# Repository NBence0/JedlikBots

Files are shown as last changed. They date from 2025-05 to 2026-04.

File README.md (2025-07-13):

# JedlikBots – Future Robotics Engineers from Győr, Hungary
<p align="center">
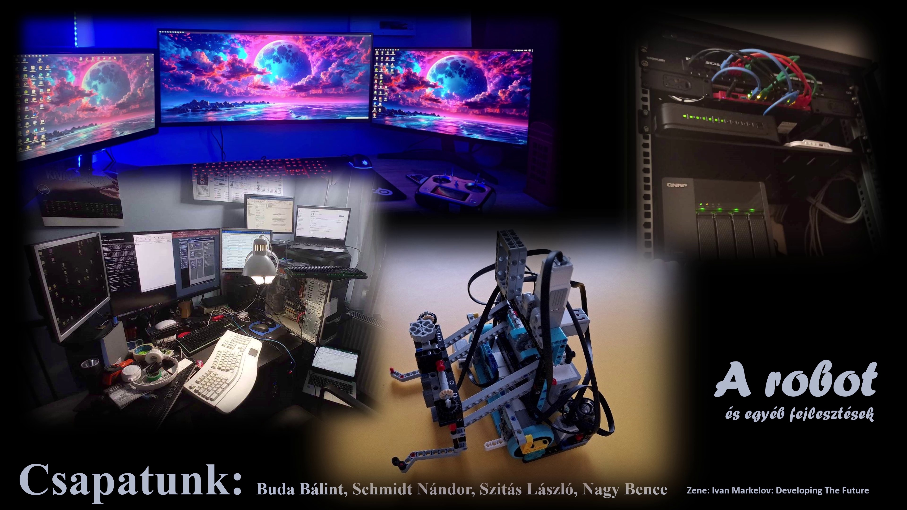
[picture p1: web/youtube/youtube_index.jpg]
JedlikBots Banner
  
</p>

Welcome to the official GitHub page of **JedlikBots**! 🎓🤖 We are the dedicated team of software development and robotics students from the Jedlik Ányos Technical School in Győr, Hungary. Our passion is to combine mechanical engineering, electronics, and software development to create innovative robotics solutions that address real-world problems. Our goal is to apply our acquired knowledge in national and international competitions and to inspire the next generation of engineers.

---

## 🚀 Our Main Project: ProBot X1 – The Next Generation of Competition Robots

The **ProBot X1** is our team's flagship project: a professional, modular robot platform specifically designed for the **WRO (World Robot Olympiad)** international competition series and other high-level technological challenges. During the robot's development, we use state-of-the-art technologies to create a truly competitive and versatile device.

<p align="center">
  ProBot X1 Prototype
  <br>
  <em>The early but functional prototype of the ProBot X1 in its development environment.</em>
</p>

---

## 🔧 Technical Deep Dive: The Anatomy of ProBot X1

The ProBot X1 is not just a robot—it's a complex system designed and built with precision engineering. Below, we provide a detailed overview of the project's technical background.

### 1. Mechanical Design and Manufacturing Philosophy

The robot's physical frame and all mechanical components are entirely custom-designed. Our design philosophy centers around **modularity**, **robustness**, and **rapid iteration**.

*   **Design Software:** We create our models in professional CAD software, where every component is designed down to the smallest detail.
*   **Manufacturing Technology:** The parts are produced using 3D printing. This allows us to test new prototypes within days and flexibly adapt the robot's structure to the specific requirements of a given competition task.
*   **Material Selection:** We use PLA for prototypes and PETG or ABS for the final, high-stress components to ensure adequate strength and durability.

| Design in CAD Software (Video) | The Finished, Printed Components |
| :---: | :---: |
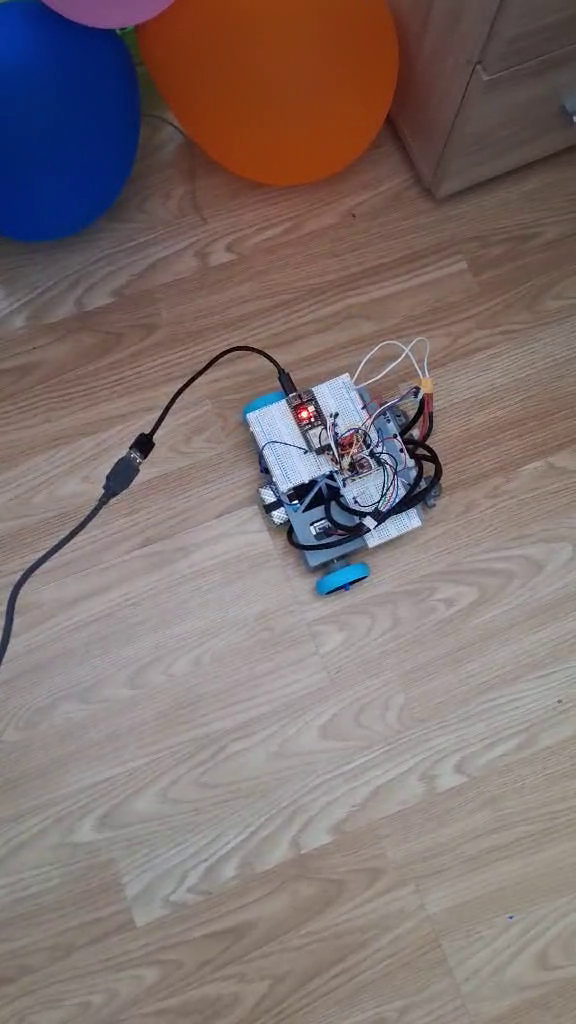
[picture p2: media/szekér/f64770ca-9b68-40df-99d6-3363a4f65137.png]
Robot Design Process Video
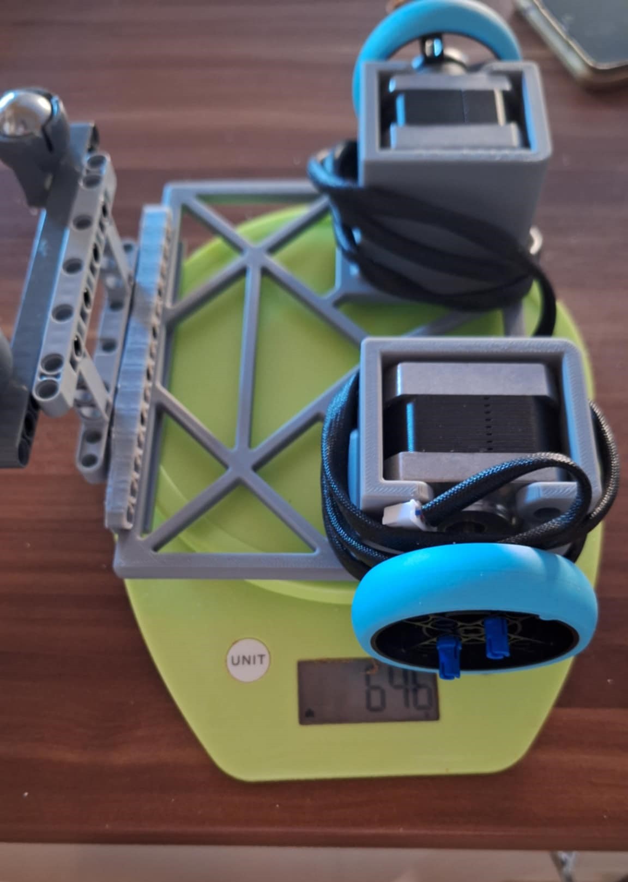
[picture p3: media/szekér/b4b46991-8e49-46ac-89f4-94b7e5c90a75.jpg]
Printed Robot Components
|  |  |
<p align="center"><em>On the left, the design process (click for video!), and on the right, the finished, printed components next to measurement instruments. The lattice structure provides optimal rigidity with minimal weight.</em></p>

### 2. Advanced Electronics and Custom-Designed PCB

The robot's brain and nervous system are comprised of a custom Printed Circuit Board (PCB) designed by us, located in the `Circuit/kicad/Robot fő nyák_v3/` folder. Our goal was to create a central board that integrates all control and sensor functions, minimizing wiring and maximizing reliability.

**The main functional blocks of the PCB:**

*   **Central Processing Unit (CPU):** The board hosts a **Raspberry Pi Compute Module 5 (CM5)**, which is responsible for computationally intensive tasks like machine vision and artificial intelligence.
*   **Real-Time Microcontroller (MCU):** An **ESP32-S3** microcontroller handles low-level, hardware-related control (motors, sensors), guaranteeing deterministic, real-time operation.
*   **Motor Control Subsystem:**
    *   Four **TMC5160** stepper motor drivers controlled via SPI for precise and silent movement. These drivers have advanced features like `StealthChop2™` for silent operation and `StallGuard2™` for sensorless homing.
    *   Multiple H-bridge outputs for driving DC motors and other actuators.
*   **Power Supply Unit (PSU):** A complex power supply providing multiple voltage levels (5V, 12V) and managing battery charging (`Battery-circuit.kicad_sch`). The system monitors the battery status and provides protection against overcharging and deep discharge.
*   **Sensor Interfaces:**
    *   **I²C Bus:** Multiple I²C devices, including a 9-axis IMU (BNO085) and an environmental sensor (BME280), are connected through an I²C multiplexer, allowing the simultaneous use of devices with the same address.
    *   **Analog-to-Digital Converter (ADC):** A high-resolution ADC (`ADS8688`) is responsible for the precise digitization of analog sensor signals (e.g., distance sensors).
*   **Peripherals:** USB hub, SD card reader, and numerous GPIO pins for modular expandability.

<p align="center">
  Prototype Electronics
  <br>
  <em>The "cable jungle"—an essential part of the prototyping phase, from which the final, clean PCB is born.</em>
</p>

### 3. Software Architecture and Intelligent Control

Hardware is only as good as the software that runs on it. The ProBot X1 is built on a sophisticated, two-tier software architecture.

#### High-Level Control (Raspberry Pi - Python)
The Python environment running on the Raspberry Pi is responsible for the robot's "intelligence."

*   **Machine Vision (OpenCV):** Our code in the `Camera/` folder implements a complete image processing pipeline:
    1.  **Image Acquisition:** Reading the frame from the camera.
    2.  **Preprocessing:** Converting the image to the HSV color space, which is more resistant to changes in lighting conditions. Applying Gaussian blur to reduce noise.
    3.  **Color and Shape Recognition:** Identifying relevant objects (e.g., colored blocks, lines) using color masking and contour detection.
    4.  **Data Extraction:** Determining the position, size, and orientation of objects in the camera's view.
*   **Decision-Making and Strategy:** Based on the processed data, the robot builds a state-space representation of its environment and plans its next moves to optimize score.

<p align="center">
  <a href="media/szek%C3%A9r/54ec2fce-310a-48c4-85d7-5ac6d85cda42.mp4">
    
  </a>
  <br>
  <em>Click the image to watch the video! Based on the camera's image, the LED strip connected to the ESP32 lights up with the corresponding color.</em>
</p>

#### Low-Level Control and Firmware (ESP32 - C++)
The C++ firmware running on the ESP32 microcontroller, developed in the `PlatformIO` environment, ensures hard real-time operation.

*   **Responsibilities:** Receiving commands from the Raspberry Pi, precise stepping of motors, continuous collection and transmission of sensor data, and critical fault handling.
*   **Communication Protocol:** A custom, packet-based UART protocol connects the two brains. The protocol, developed in our `robot modells/v1.0/Full_uart_communication_logic_v2/` project, has the structure: `[START_BYTE, COMMAND_ID, PAYLOAD_LENGTH, PAYLOAD..., CHECKSUM]`. This structure guarantees data integrity and robust operation.

---

## 👥 Our Team

Meet the driving force behind JedlikBots, the students who power the project:

| Photo | Name | Role & Expertise |
| :---: | :--- | :--- |
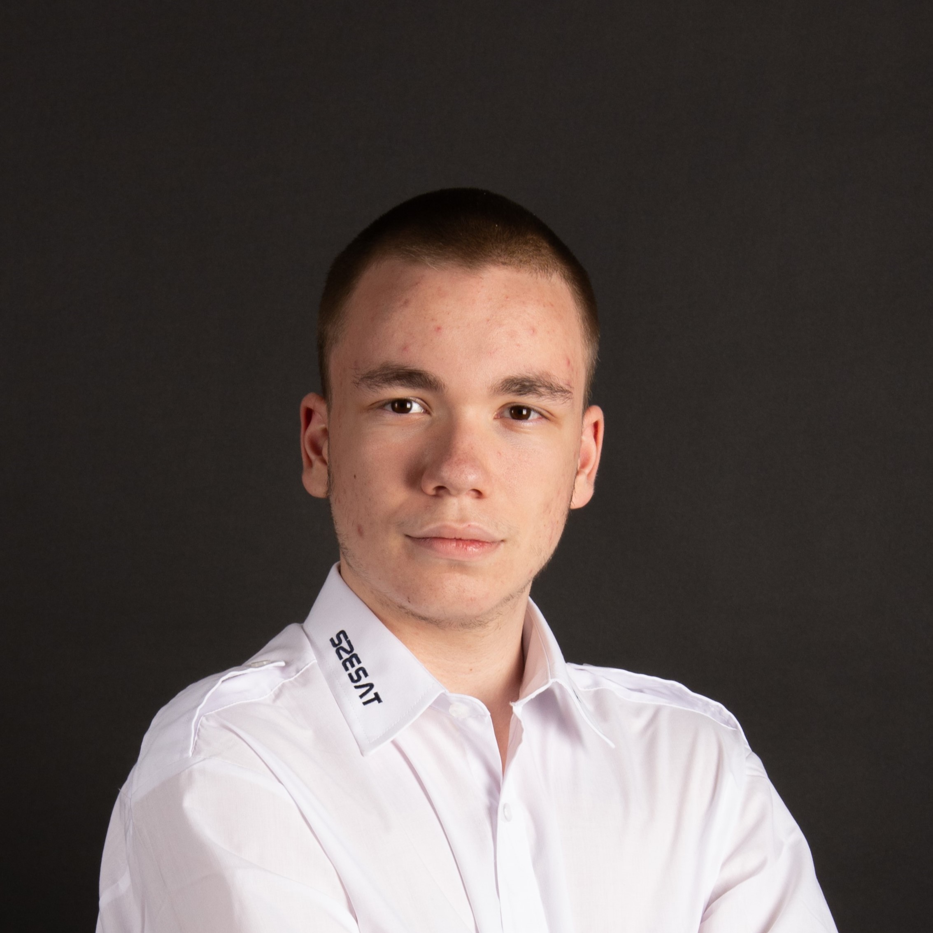
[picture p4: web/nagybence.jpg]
|  | **Bence Nagy** | **Software Developer.** Specializes in sensor data processing, embedded systems programming, and 3D modeling. Bence is responsible for the robot's hardware abstraction layer and the design of its mechanical components. |
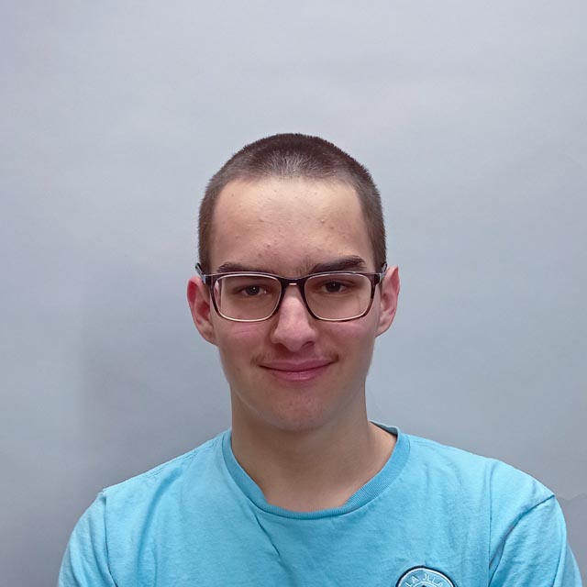
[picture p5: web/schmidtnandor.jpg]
|  | **Nándor Schmidt** | **Electronics Designer & Firmware Developer.** The expert on the embedded systems behind the robots' "brains." He designs the PCBs and writes the low-level firmware, ensuring a perfect harmony between hardware and software. |
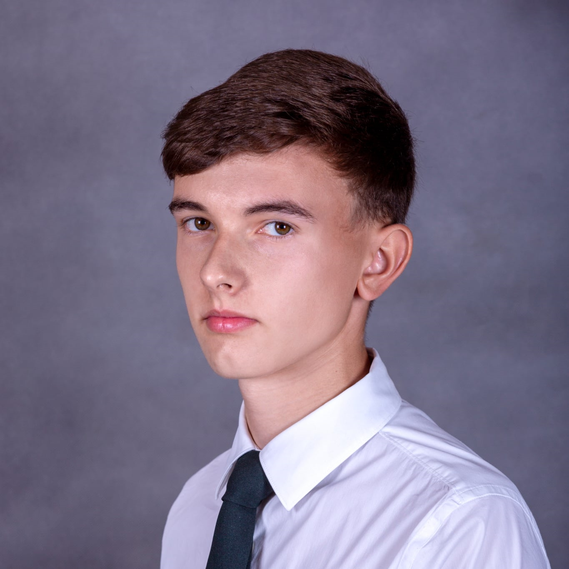
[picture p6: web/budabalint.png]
|  | **Bálint Buda** | **AI & Communications Developer.** Bálint is responsible for implementing machine learning algorithms and for the robot's wired and wireless communication. |

---

## 🏆 Competition Results and Goals

We are proud of our achievements so far and have set even bigger goals for ourselves.

*   **🥈 WRO 2025 Regional Final, Budapest - 2nd Place (May 2025)**
    *   We entered our first WRO competition with a LEGO Mindstorms EV3-based robot and achieved 2nd place in the Budapest regional final. This success qualified us for the national final but also highlighted the limitations of our current technology. With the new, professional ProBot X1, our goal is the World Final!

<p align="center">
  <a href="https://www.youtube.com/watch?v=QTDwxr4dkFA">
    WRO 2025 LEGO Robot
  </a>
  <br>
  <em>Click the image to watch our LEGO robot's competition run!</em>
</p>

---

## ❤️ Support the Engineers of the Future!

Developing the ProBot X1 and participating in international competitions require significant financial and technical resources. Our goal is to perform well at the WRO World Final, which requires building a world-class robot. This is where we need your help!

<p align="center">
  <a href="media/szek%C3%A9r/20250708_144151.mp4" title="Click to watch the video!">
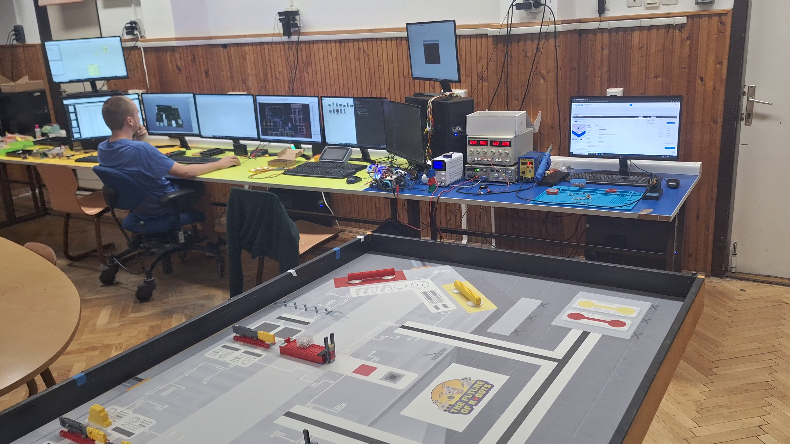
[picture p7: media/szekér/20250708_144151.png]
Development Workshop Video
    
  </a>
  <br>
  <em>Click the image to see our workshop in action! This is where ideas and robots are born.</em>
</p>

### How You Can Help

1.  **With Equipment:** Modern components are essential for our project. Every single piece of donated equipment is a huge help. What we need most:
    *   **Microcontrollers:** Raspberry Pi (any version, including Compute Modules), STM-based boards.
    *   **Motors and Controllers:** Stepper motors, DC motors, servos, motor controllers.
    *   **Sensors:** Precision color and distance sensors, camera modules.
    *   **Materials:** 3D printer filament (PLA, PETG, 1.75 mm), breadboards, cables.
    *   **Measurement Tools:** Logic analyzer for debugging, oscilloscope.

2.  **With Professional Mentorship:** If you are an experienced engineer or developer and would like to share your knowledge, please contact us! A piece of good advice can be invaluable.

3.  **With Financial Support:** Your financial contribution can directly support the purchase of components and our travel to competitions.
### Contact
If you would like to contribute to our success, please write to us!
*   **Email:** nagy.bence1@students.jedlik.eu
*   **Phone:** +36 30 368 8136

---

## 🙏 Our Sponsors

We are deeply grateful to our current sponsors who believe in us and support our work!

<p align="center">
  <a href="https://malnapc.hu/" target="_blank" rel="noopener noreferrer" style="margin-right: 20px;">
    Málna PC & Raspberry Pi Shop Logo
  </a>
  <a href="https://master3d.hu/" target="_blank" rel="noopener noreferrer">
    Master3D Logo
  </a>
</p>

---

## 📂 Repository Contents

This repository documents the entire work of the JedlikBots team. You can find our projects in the following folders:

*   **`/Circuit/`**: Contains the designs for our custom Printed Circuit Boards (PCBs) in KiCad and Altium formats.
*   **`/Robot 3d/`**: 3D models of the robot's mechanical parts (STL, STP files).
*   **`/robot modells/`**: Various software modules and experimental programs that implement the robot's functions (PlatformIO projects).
*   **`/Camera/`**: Python scripts related to machine vision.
*   **`/media/`**: Images and videos of the robot, the team, and the competitions.
*   **`/web/`**: The source code for the team's official website.

**Thank you for your time! Follow our work and cheer for us at the next competition!**
# JedlikBots – A Jövő Robotikai Mérnökei Győrből
<p align="center">
  JedlikBots Banner
</p>

---
---

Üdvözlünk a **JedlikBots** hivatalos GitHub oldalán! 🎓🤖 Mi vagyunk a Győri Jedlik Ányos Technikum szoftverfejlesztő és robotika iránt elkötelezett diákcsapata. Szenvedélyünk a gépészet, az elektronika és a szoftverfejlesztés ötvözése, amellyel innovatív, valós problémákra választ adó robotikai megoldásokat hozunk létre. Célunk, hogy a megszerzett tudást hazai és nemzetközi versenyeken kamatoztassuk, és inspiráljuk a jövő mérnökgenerációját.

---

## 🚀 Fő Projektünk: ProBot X1 – A Versenyrobot Új Generációja

A **ProBot X1** a csapatunk zászlóshajója: egy professzionális, moduláris robotplatform, amelyet kifejezetten a **WRO (World Robot Olympiad)** nemzetközi versenysorozatra, valamint más magas szintű technológiai kihívásokra terveztünk. A robot fejlesztése során a legmodernebb technológiákat alkalmazzuk, hogy egy valóban versenyképes és sokoldalú eszközt hozzunk létre.

<p align="center">
  ProBot X1 Prototípus
  <br>
  <em>A ProBot X1 korai, de működő prototípusa a fejlesztői környezetben.</em>
</p>

---

## 🔧 Technikai Mélymerülés: A ProBot X1 Anatómája

A ProBot X1 nem csupán egy robot – egy komplex, precíziós mérnöki munkával megtervezett és épített rendszer. Az alábbiakban részletesen bemutatjuk a projekt műszaki hátterét.

### 1. Mechanikai Tervezés és Gyártásfilozófia

A robot fizikai váza és minden mechanikai eleme teljes mértékben egyedi tervezésű. A tervezési filozófiánk középpontjában a **modularitás**, a **robusztusság** és a **gyors iterálhatóság** áll.

*   **Tervező Szoftver:** A modelleket professzionális CAD szoftverekben készítjük, ahol minden alkatrészt a legapróbb részletekig megtervezünk.
*   **Gyártástechnológia:** Az alkatrészeket 3D nyomtatással állítjuk elő. Ez lehetővé teszi, hogy napok alatt új prototípusokat teszteljünk, és a robotot rugalmasan az adott versenyfeladat specifikus igényeihez igazítsuk.
*   **Anyagválasztás:** A prototípusokhoz PLA-t, a végleges, nagy igénybevételnek kitett alkatrészekhez pedig PETG-t vagy ABS-t használunk a megfelelő szilárdság és tartósság érdekében.

| Tervezés a CAD Szoftverben (Videó) | A Kész, Nyomtatott Alkatrészek |
| :---: | :---: |
| <a href="media/szek%C3%A9r/f64770ca-9b68-40df-99d6-3363a4f65137.mp4">Robot Tervezési Folyamat Videó</a> | Kinyomtatott Robot Alkatrészek |
<p align="center"><em>Bal oldalon a tervezési folyamat (kattints a videóért!), jobb oldalon a kész, nyomtatott alkatrészek a mérőműszerek mellett. A rácsszerkezet optimális merevséget biztosít minimális súly mellett.</em></p>

### 2. Fejlett Elektronika és Egyedi Tervezésű NyÁK

A robot agyát és idegrendszerét egy általunk, a `Circuit/kicad/Robot fő nyák_v3/` mappában tervezett egyedi nyomtatott áramkör (PCB) alkotja. A célunk egy olyan központi panel létrehozása volt, amely integrálja az összes vezérlési és szenzorikai funkciót, minimalizálva a kábelezést és maximalizálva a megbízhatóságot.

**A NyÁK fő funkcionális blokkjai:**

*   **Központi Feldolgozó Egység (CPU):** A panel fogad egy **Raspberry Pi Compute Module 5 (CM5)** kártyát, amely a nagy számítási igényű feladatokért, mint a gépi látás és a mesterséges intelligencia, felel.
*   **Valós Idejű Mikrokontroller (MCU):** Egy **ESP32-S3** mikrokontroller végzi a hardverközeli, alacsony szintű vezérlést (motorok, szenzorok), garantálva a determinisztikus, valós idejű működést.
*   **Motorvezérlő Alrendszer:**
    *   4 darab, SPI-on keresztül vezérelt **TMC5160** léptetőmotor-meghajtó a precíz és csendes mozgásért. Ezen meghajtók olyan fejlett funkciókkal bírnak, mint a `StealthChop2™` a hangtalan működésért és a `StallGuard2™` a szenzor nélküli végállás-érzékelésért.
    *   Több, H-híddal ellátott kimenet DC motorok és egyéb aktuátorok meghajtásához.
*   **Energiaellátás (PSU):** Egy komplex, több feszültségszintet (5V, 12V) biztosító tápegység, amely az akkumulátor töltését is menedzseli (`Battery-circuit.kicad_sch`). A rendszer figyeli az akkumulátor állapotát, és védelmet nyújt a túltöltés és mélykisülés ellen.
*   **Szenzor Interfészek:**
    *   **I²C Busz:** Több I²C eszköz, köztük egy 9 tengelyes IMU (BNO085) és egy környezeti szenzor (BME280) csatlakozik egy I²C multiplexeren keresztül, amely lehetővé teszi az azonos című eszközök egyidejű használatát.
    *   **Analóg-Digitális Konverter (ADC):** Egy nagy felbontású ADC (`ADS8688`) felel az analóg szenzorok (pl. távolságmérők) jeleinek precíz digitalizálásáért.
*   **Perifériák:** USB hub, SD kártya olvasó, és számos GPIO kivezetés a moduláris bővíthetőség érdekében.

<p align="center">
  Prototípus Elektronika
  <br>
  <em>A "kábel dzsungel" – a prototípus fázis elengedhetetlen része, amelyből a végleges, letisztult PCB megszületik.</em>
</p>

### 3. Szoftver Architektúra és Intelligens Vezérlés

A hardver csak annyit ér, amennyit a szoftver kihoz belőle. A ProBot X1 egy kifinomult, kétlépcsős szoftveres architektúrára épül.

#### Magas Szintű Vezérlés (Raspberry Pi - Python)
A Raspberry Pi-on futó Python környezet felel a robot "intelligenciájáért".

*   **Gépi Látás (OpenCV):** A `Camera/` mappában található kódjaink egy komplett képfeldolgozási folyamatot valósítanak meg:
    1.  **Kép Begyűjtése:** A kamera képének beolvasása.
    2.  **Előfeldolgozás:** A kép konvertálása HSV színtérbe, amely jobban ellenáll a fényviszonyok változásainak. Gauss-elmosás alkalmazása a zaj csökkentésére.
    3.  **Szín- és Alakfelismerés:** Színmaszkolással és kontúrkereséssel azonosítjuk a releváns objektumokat (pl. színes kockák, vonalak).
    4.  **Adatkinyerés:** Meghatározzuk az objektumok pozícióját, méretét és orientációját a kamera képén.
*   **Döntéshozatal és Stratégia:** A feldolgozott adatok alapján a robot egy állapottér-reprezentációt épít a környezetéről, és ez alapján tervezi meg a következő lépéseit, optimalizálva a pontszerzést.

<p align="center">
  <a href="media/szek%C3%A9r/54ec2fce-310a-48c4-85d7-5ac6d85cda42.mp4">
    
  </a>
  <br>
  <em>Kattints a képre a videó megtekintéséhez! A kamera képe alapján az ESP32-re kötött LED-szalag a megfelelő színnel világít.</em>
</p>

#### Alacsony Szintű Vezérlés és Firmware (ESP32 - C++)
Az ESP32 mikrokontrolleren futó, `PlatformIO` környezetben fejlesztett C++ firmware biztosítja a kőkemény valós idejű működést.

*   **Feladatai:** Parancsok fogadása a Raspberry Pi-tól, motorok precíz léptetése, szenzoradatok folyamatos gyűjtése és továbbítása, valamint a kritikus hibakezelés.
*   **Kommunikációs Protokoll:** A két agy között egy egyedi, csomagalapú UART protokoll biztosítja a kapcsolatot. A `robot modells/v1.0/Full_uart_communication_logic_v2/` projektünkben kidolgozott protokoll felépítése: `[START_BYTE, PARANCS_ID, ADAT_HOSSZ, ADATOK..., ELLENŐRZŐ_ÖSSZEG]`. Ez a struktúra garantálja az adatok sértetlenségét és a robusztus működést.

---

## 👥 Csapatunk

Ismerd meg a JedlikBots motorjait, a diákokat, akik a projekt mögött állnak:

| Fotó | Név | Szerepkör és szakterület |
| :---: | :--- | :--- |
|  | **Nagy Bence** | **Szoftverfejlesztő.** Specializációja a szenzoradatok feldolgozása, a beágyazott rendszerek programozása és a 3D modellezés. Bence felelős a robot hardverközeli szoftverrétegéért és a mechanikai elemek tervezéséért. |
|  | **Schmidt Nándor** | **Elektronikai Tervező & Firmware Fejlesztő.** A robot "agya" mögött álló beágyazott rendszerek szakértője. Ő tervezi a PCB-ket és írja az alacsony szintű firmware-t, biztosítva a hardver és szoftver tökéletes összhangját. |
|  | **Buda Bálint** | **AI & Kommunikációs Fejlesztő.** Bálint felelős a gépi tanulási algoritmusok implementálásáért és a robotok vezetékes és vezeték nélküli kommunikációjáért. |

---

## 🏆 Versenyeredményeink és Céljaink

Büszkék vagyunk az eddig elért sikereinkre, és még nagyobb célokat tűztünk ki magunk elé.

*   **🥈 WRO 2025 Regionális Döntő, Budapest - 2. helyezés (2025. május)**
    *   Az első WRO versenyünkön egy LEGO Mindstorms EV3 alapú robottal indultunk, és a budapesti regionális döntőben 2. helyezést értünk el. Ez a siker kvalifikált minket a nemzeti döntőbe, de rávilágított a jelenlegi technológiánk korlátaira. Az új, professzionális ProBot X1 robottal a célunk a világdöntő!

<p align="center">
  <a href="https://www.youtube.com/watch?v=QTDwxr4dkFA">
    WRO 2025 LEGO Robot
  </a>
  <br>
  <em>Kattints a képre a LEGO robotunk versenyfutamának megtekintéséhez!</em>
</p>

---

## ❤️ Támogasd a Jövő Mérnökeit!

A ProBot X1 fejlesztése és a nemzetközi versenyeken való részvétel komoly anyagi és technikai erőforrásokat igényel. Célunk a WRO világdöntőn való eredményes szereplés, amihez egy világszínvonalú robot megépítése szükséges. Itt kérjük a te segítségedet!

<p align="center">
  <a href="media/szek%C3%A9r/20250708_144151.mp4" title="Kattints a videó megtekintéséhez!">
    Fejlesztői Műhely Videó
  </a>
  <br>
  <em>Kattints a képre, és nézd meg a műhelyünket működés közben! Itt születnek az ötletek és a robotok.</em>
</p>

### Hogyan Segíthetsz?

1.  **Eszközökkel:** A projektünkhöz elengedhetetlenek a modern alkatrészek. Minden egyes felajánlott eszköz óriási segítséget jelent. Amire a legnagyobb szükségünk van:
    *   **Mikrokontrollerek:** Raspberry Pi (bármely változat, akár Compute Module is), STM-alapú panelek.
    *   **Motorok és vezérlők:** Léptetőmotorok, DC motorok, szervók, motorvezérlők.
    *   **Szenzorok:** Precíziós szín- és távolságérzékelők, kameramodulok.
    *   **Alapanyagok:** 3D nyomtató filament (PLA, PETG, 1.75 mm), próbapanelek, kábelek.
    *   **Mérőműszerek:** Logikai analizátor a hibakereséshez, oszcilloszkóp.

2.  **Szakmai Mentorálással:** Ha tapasztalt mérnök, fejlesztő vagy, és szívesen megosztanád a tudásod, vedd fel velünk a kapcsolatot! Egy-egy jó tanács aranyat érhet.

3.  **Anyagi Támogatással:** Pénzügyi hozzájárulásoddal közvetlenül támogathatod az alkatrészek beszerzését és a versenyekre való utazásunkat.

### Kapcsolat
Ha szeretnél hozzájárulni a sikereinkhez, írj nekünk!
*   **Email:** nagy.bence1@students.jedlik.eu
*   **Telefonszám:** +36 30 368 8136

---

## 🙏 Támogatóink

Hálásan köszönjük eddigi támogatóinknak, akik hisznek bennünk és segítik a munkánkat!

<p align="center">
  <a href="https://malnapc.hu/" target="_blank" rel="noopener noreferrer" style="margin-right: 20px;">
    Málna PC és Raspberry Pi bolt logó
  </a>
  <a href="https://master3d.hu/" target="_blank" rel="noopener noreferrer">
    Master3D logó
  </a>
</p>

---

## 📂 A Repository Tartalma

Ez a repository a JedlikBots csapat teljes munkáját dokumentálja. Az alábbi mappákban találod a projektjeinket:

*   **`/Circuit/`**: A robotunkhoz tervezett egyedi nyomtatott áramkörök (PCB) tervei KiCad és Altium formátumban.
*   **`/Robot 3d/`**: A robot mechanikai alkatrészeinek 3D modelljei (STL, STP fájlok).
*   **`/robot modells/`**: Különböző szoftveres modulok és kísérleti programok, amelyek a robot funkcióit valósítják meg (PlatformIO projektek).
*   **`/Camera/`**: A gépi látással kapcsolatos Python scriptek.
*   **`/media/`**: Képek és videók a robotról, a csapatról és a versenyekről.
*   **`/web/`**: A csapat hivatalos weboldalának forráskódja.

**Köszönjük, hogy időt szántál ránk! Kövesd a munkánkat, és szurkolj nekünk a következő versenyen!**

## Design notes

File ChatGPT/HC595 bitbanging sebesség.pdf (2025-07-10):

# HC595 bitbanging sebesség

3db hc595 öt öt bitbangingal milyen gyorsan udok frissíteni benne egy regisztert?

A 74HC595 shift regiszter bitbangingos (szoftveres SPI) vezérlése esetén a frissítési sebesség – azaz hogy milyen gyorsan tudsz egy 8 bites regisztert „shiftelni” és frissíteni – elsősorban a mikrokontroller órajelétől, a kód optimalizáltságától, és a GPIO műveletek sebességétől függ.

## 🧮 Alap: Mennyire gyors egy frissítés?

Egy 74HC595 shift regiszter esetén:

### 1 bit átvitele: 1 × data set + 1 × clock pulse = kb. 2-3 GPIO művelet 8 bit: 8 × 2 = kb. 16 GPIO művelet 3 db 595 esetén: 24 bit ⇒ kb. 48 GPIO művelet

Frissítéshez még 1 latch impulzus is kell

Tehát egy teljes frissítés: kb. 50-55 GPIO művelet

## 🕒 Milyen gyors a GPIO?

Platform | GPIO művelet idő | Teljes frissítési idő (becslés) | Max. frissítési frekvencia
AVR (pl. ATmega328, Arduino Uno, 16 MHz) | ~1 µs / művelet (bitbanging C-ben) | ~50 µs | ~20 kHz
STM32 (pl. STM32F1, 72 MHz, optimalizált) | ~0.1-0.2 µs / művelet | ~5-10 µs | ~100-200 kHz
ESP32 (240 MHz) | ~0.05-0.1 µs / művelet | ~2.5-5 µs | ~200-400 kHz

## 🧠 Optimalizálási lehetőségek:

1. Alacsony szintű kód (port manpuláció pl. PORTB |= (1<<PB0);) sokkal gyorsabb, mint digitalWrite.
2. Inline assembly akár 1-2x gyorsabb lehet.
3. Timer-alapú frissítés ha precíz időzítés kell.
4. SPI periféria használata (ha van): HW SPI akár 1–10 MHz sebességgel is tud dolgozni, ami nagyságrenddel gyorsabb a bitbangingnél.

## Példa: Arduino Uno bitbanging tempó (becslés)

Printed using ChatGPT to PDF, (https://pdfcrowd.com/chatgpt-to-pdf/?ref=chatgpt) powered by PDFCrowd HTML to PDF API. (https://pdfcrowd.com/api/html-to-pdf-api/?ref=chatgpt) | 1/27

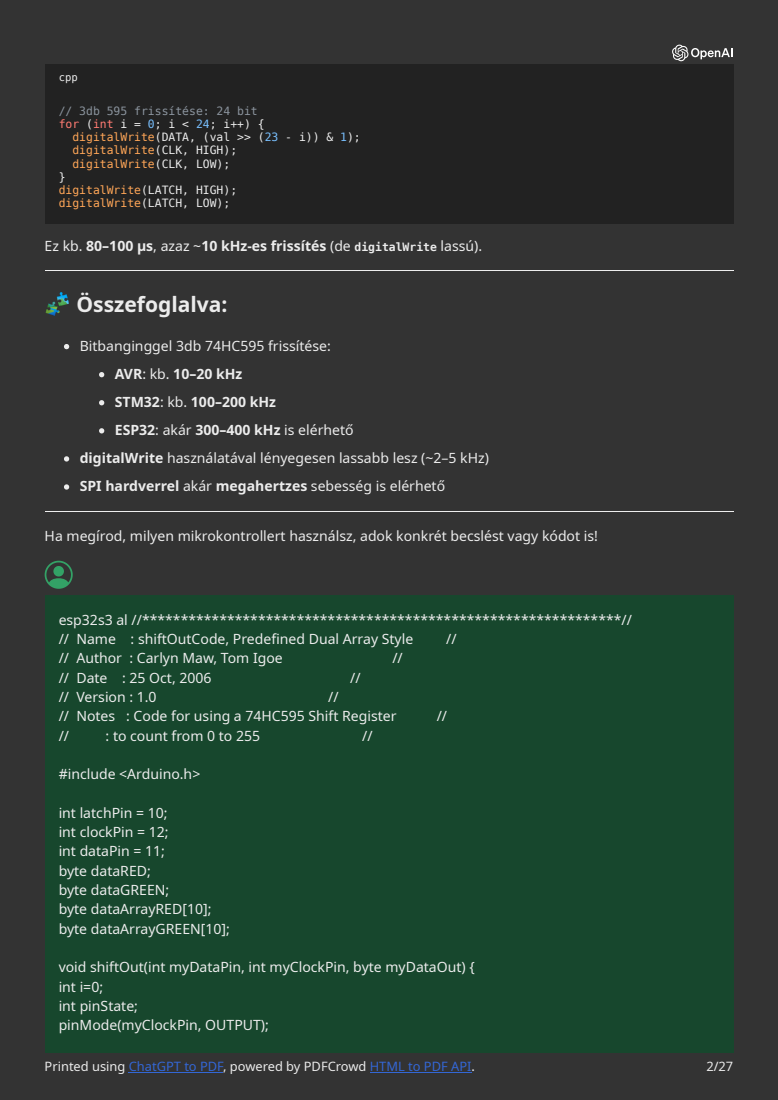
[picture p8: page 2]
cpp; esp32s3 al //**************************************************************//; // Name : shiftOutCode, Predefined Dual Array Style; // Author : Carlyn Maw, Tom Igoe; // Date : 25 Oct, 2006; // Version : 1.0; // Notes : Code for using a 74HC595 Shift Register; : to count from 0 to 255; #include <Arduino.h>; int latchPin = 10; int clockPin = 12; int dataPin = 11; byte dataRED; byte dataGREEN; byte dataArrayRED[10]; byte dataArrayGREEN[10];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

// 3db 595 frissítése: 24 bit
for (int i = 0; i < 24; i++) {
digitalWrite(DATA, (val >> (23 - i)) & 1);
digitalWrite(CLK, HIGH);
digitalWrite(CLK, LOW);
digitalWrite(LATCH, HIGH);
digitalWrite(LATCH, LOW);

Ez kb. 80–100 µs, azaz ~10 kHz-es frissítés (de digitalWrite lassú).
🧩 Összefoglalva:

Bitbanginggel 3db 74HC595 frissítése:
AVR: kb. 10–20 kHz
STM32: kb. 100–200 kHz
ESP32: akár 300–400 kHz is elérhető
digitalWrite használatával lényegesen lassabb lesz (~2–5 kHz)
SPI hardverrel akár megahertzes sebesség is elérhető

Ha megírod, milyen mikrokontrollert használsz, adok konkrét becslést vagy kódot is!

void shiftOut(int myDataPin, int myClockPin, byte myDataOut) {
int i=0;
int pinState;
pinMode(myClockPin, OUTPUT);

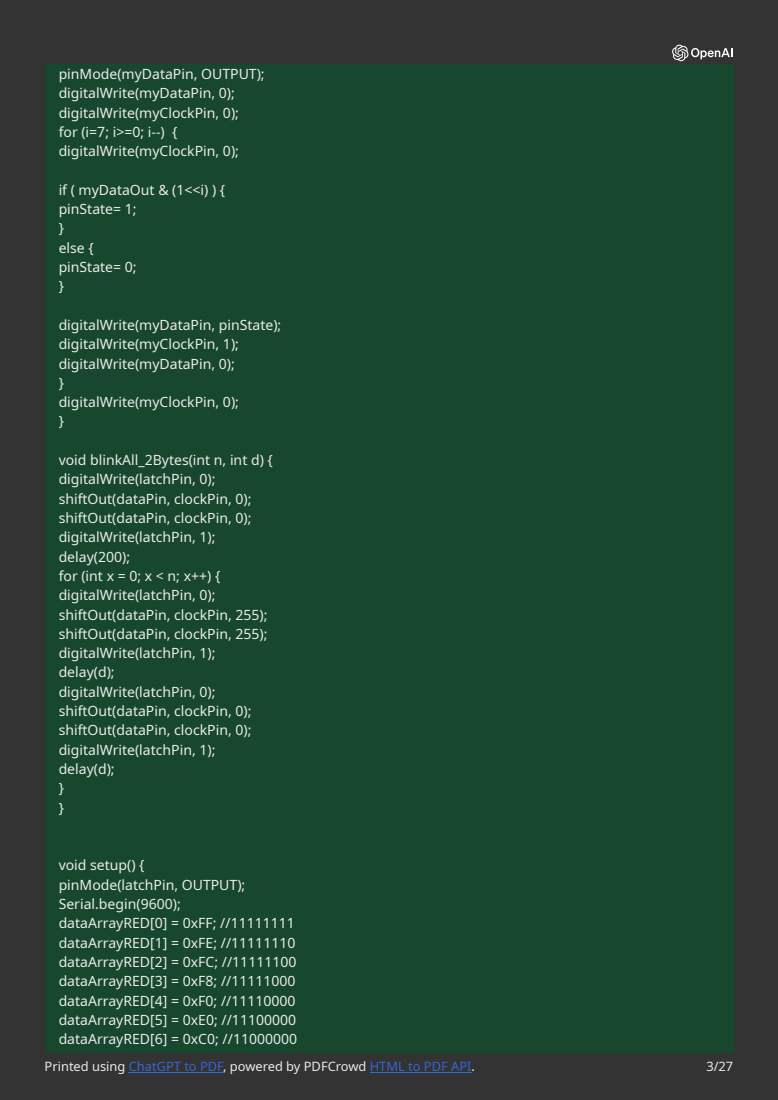
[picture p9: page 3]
pin; Pin; digit; alW; rit; Clo; }digit; oid; blin; All_; hift; clo; ela; rial.b; gin; rin; sin

; if ( myDataOut & (1<<i) ) { pinState= 1; }else { pinState= 0; }digitalWrite(myDataPin, pin

dataArrayRED[7] = 0x80; //10000000 dataArrayRED[8] = 0x00; //00000000 dataArrayRED[9] = 0xE0; //11100000

dataArrayGREEN[0] = 0xFF; //11111111 dataArrayGREEN[1] = 0x7F; //01111111 dataArrayGREEN[2] = 0x3F; //00111111 dataArrayGREEN[3] = 0x1F; //00011111 dataArrayGREEN[4] = 0x0F; //00001111 dataArrayGREEN[5] = 0x07; //00000111 dataArrayGREEN[6] = 0x03; //00000011 dataArrayGREEN[7] = 0x01; //00000001 dataArrayGREEN[8] = 0x00; //00000000 dataArrayGREEN[9] = 0x07; //00000111 blinkAll_2Bytes(2,200);
}

void loop() {
for (int j = 0; j < 10; j++) {
dataRED = dataArrayRED[j];
dataGREEN = dataArrayGREEN[j]; digitalWrite(latchPin, 0); shiftOut(dataPin, clockPin, dataGREEN); shiftOut(dataPin, clockPin, dataRED); digitalWrite(latchPin, 1);
delay(50); // ennyi időnként küld adatot }

} ezzel a kóddal ha a delayeket kiszedem

Kiváló! Nézzük meg pontosan, milyen gyorsan tudod frissíteni a 74HC595 regisztereket ezzel a bitbanging kóddal ESP32-S3-on, ha minden delay()-t kiszedsz.

📌 Részletek a kódból:

Ebben a ciklusban:

cpp

digitalWrite(latchPin, 0);
shiftOut(dataPin, clockPin, dataGREEN); // 8 bit shiftOut(dataPin, clockPin, dataRED); // 8 bit digitalWrite(latchPin, 1);

Egy frissítéshez 2 byte-ot shiftelsz be = 16 bit = 16 ciklus a shiftOut()-ban. És minden ciklusban:

Printed using ChatGPT to PDF, (https://pdfcrowd.com/chatgpt-to-pdf/?ref=chatgpt) powered by PDFCrowd HTML to PDF API. (https://pdfcrowd.com/api/html-to-pdf-api/?ref=chatgpt) | 4/27

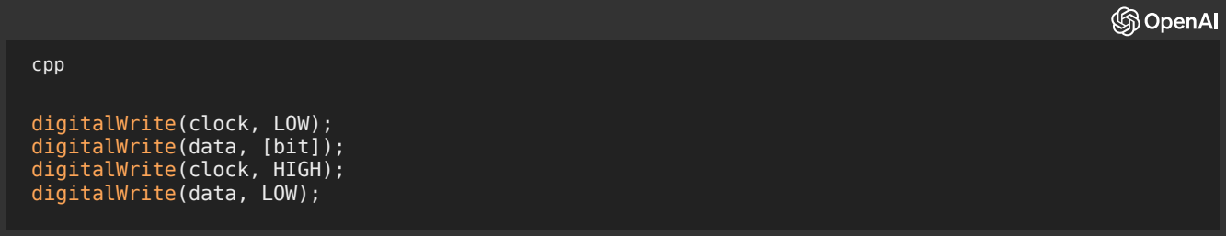
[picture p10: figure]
cpp; digitalWrite(clock, LOW); digitalWrite(data, [bit]); digitalWrite(clock, HIGH); digitalWrite(data, LOW);

Ez kb. 4 db digitalWrite() hívás / bit, tehát összesen:

👉 16 bit * 4 = 64 digitalWrite()

### 2 digitalWrite() a latch kezeléséhez

= összesen ~66 GPIO művelet/frissítés

⚡ Milyen gyors a digitalWrite() ESP32-S3-on?

Az Arduino digitalWrite() ESP32-n sokkal lassabb, mint a hardver GPIO műveletek. Átlagos sebessége: kb. 1–2 µs per hívás ESP32-n (mért, nem elméleti).
Ha 66 hívás/frissítés × 1.5 µs = ~100 µs / frissítés
Ez azt jelenti, hogy maximálisan kb. 10 kHz frissítés érhető el ezzel a kóddal delay nélkül.

🧪 Ha kiszeded a delayeket:

cpp

void loop() {
for (int j = 0; j < 10; j++) { dataRED = dataArrayRED[j];
dataGREEN = dataArrayGREEN[j]; digitalWrite(latchPin, 0); shiftOut(dataPin, clockPin, dataGREEN); shiftOut(dataPin, clockPin, dataRED); digitalWrite(latchPin, 1);
// delay(50); <-- KISZEDVE
}
}

Ez a loop 10× 2 byte shiftelés = 660 digitalWrite() hívás egy loop() ciklusban. Ha 1 loop kb. 1 ms, akkor frissítési frekvenciád:
✅ ~10.000 frissítés/sec = 10 kHz

🔧 Hogyan lehet gyorsítani?

### 1. Használj direkt GPIO írást (ESP32-n):

cpp

#define DATA_PIN 11

#define CLOCK_PIN 12

#define DATA_HIGH GPIO.out_w1ts = (1 << DATA_PIN)

#define DATA_LOW GPIO.out_w1tc = (1 << DATA_PIN)

Printed using ChatGPT to PDF, (https://pdfcrowd.com/chatgpt-to-pdf/?ref=chatgpt) powered by PDFCrowd HTML to PDF API. (https://pdfcrowd.com/api/html-to-pdf-api/?ref=chatgpt) | 5/27

#define CLOCK_HIGH GPIO.out_w1ts = (1 << CLOCK_PIN)

#define CLOCK_LOW GPIO.out_w1tc = (1 << CLOCK_PIN)

Ezzel akár ~10-20x gyorsabb lehet, és elérhetsz 100–200 kHz frissítést is.

### 2. Használj hardver SPI-t:

cpp

SPI.begin(clockPin, MISO, dataPin, latchPin);

digitalWrite(latchPin, LOW); SPI.transfer(dataGREEN);
SPI.transfer(dataRED);
digitalWrite(latchPin, HIGH);

SPI sebesség akár 10 MHz is lehet. Akkor egy 2 byte shift <2 µs → akár 500.000 frissítés/másodperc is lehet!

📋 Összefoglalás:

Módszer | Max. frissítés (2 byte) | Megjegyzés
digitalWrite() bitbanging | ~10 kHz | Kódod most ezt tudja
Direkt GPIO hozzáférés | ~100–200 kHz | GPIO.out_w1ts, w1tc
Hardver SPI | ~500 kHz – 10 MHz | Maximális tempó

Ha szeretnéd, segítek átírni a kódot gyorsabb GPIO műveletekre vagy SPI vezérlésre.

Ha 1 MHz-es frissítést mértél a shiftOut()-os kódoddal ESP32-S3-on, az nagyon valószínű, de nem a klasszikus Arduino shiftOut() függvénnyel – hacsak nem optimalizáltad valahogy, vagy nem használod belsőleg az ESP32 gyors GPIO-t.
Vizsgáljuk meg pontosan, mi lehetséges, és mit mérhettél:

## 🧪 Ha 1 MHz sebességet mértél

Ez azt jelenti:

### 1 teljes regiszter frissítés (2 byte → 16 bit) = 1 µs × 16 = 16 µs 1 MHz esetén tehát: minden bit 1 µs alatt ki van tolva

Ez lehetséges ESP32-n, de nem a klasszikus Arduino shiftOut()-lal, ami digitalWrite()-et használ, ami 1–2 µs / művelet, és bitenként legalább 4 ilyen hívást igényel, azaz ~6–8 µs/bit ⇒ max ~125–250 kHz.

Printed using ChatGPT to PDF, (https://pdfcrowd.com/chatgpt-to-pdf/?ref=chatgpt) powered by PDFCrowd HTML to PDF API. (https://pdfcrowd.com/api/html-to-pdf-api/?ref=chatgpt) | 6/27

## ✅ Tehát: mikor reális az 1 MHz?

1. 🔥 Ha a shiftOut()-ot saját magad írtad direkt GPIO írással:

cpp

#define DATA_HIGH GPIO.out_w1ts = (1 << dataPin) #define DATA_LOW GPIO.out_w1tc = (1 << dataPin) #define CLK_HIGH GPIO.out_w1ts = (1 << clockPin)

#define CLK_LOW GPIO.out_w1tc = (1 << clockPin)

Akkor a bitbanging sebesség valóban lehet akár 1 MHz vagy gyorsabb.

2. 🧠 VAGY: Használod az ESP32 saját shiftOut() implementációját?

Az ESP32 Arduino core belsőleg újradefiniálhatja a shiftOut()-ot úgy, hogy nem digitalWrite()-et használ, hanem port manipulationt, amivel akár 1–2 MHz is simán elérhető.

Ellenőrizheted így:

cpp

void setup() {
Serial.begin(115200);
Serial.println((uintptr_t)&shiftOut); // megmondja, hol van shiftOut
}

Ha nem az AVR shiftOut() címe, akkor valószínűleg gyors ESP32-specifikus implementációt használsz.

## ️ Kipróbálható: időzített mérés

cpp

unsigned long t1 = micros(); shiftOut(dataPin, clockPin, dataGREEN); shiftOut(dataPin, clockPin, dataRED);
unsigned long t2 = micros();

Serial.println(t2 - t1); // hány µs volt a 16 bit shift

Ha itt t2 - t1 ~ 16 µs, akkor tényleg 1 MHz körüli a bitsebességed.

## 💡 Következtetés:

Ha 1 MHz-et mértél, akkor:
✅ Lehetséges ESP32-n,
✅ De csak ha:

nem az eredeti, régi AVR-es shiftOut()-ot használod, VAGY

Printed using ChatGPT to PDF, (https://pdfcrowd.com/chatgpt-to-pdf/?ref=chatgpt) powered by PDFCrowd HTML to PDF API. (https://pdfcrowd.com/api/html-to-pdf-api/?ref=chatgpt) | 7/27

saját gyors GPIO-alapú bitbanginget használsz, VAGY
az ESP32 Arduino core egy gyorsabb shiftOut()-ot definiál

📌 Ha szeretnéd, megmutatom, hogyan írj ultragyors saját shiftOut-ot ESP32-re, akár 10 MHz-ig (vagy

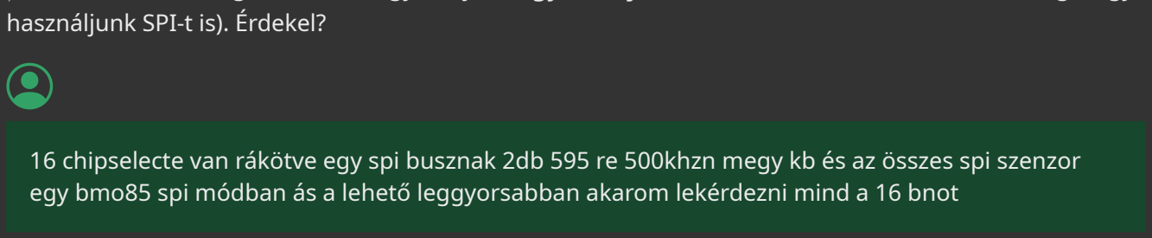
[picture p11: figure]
használjunk SPI-t is). Érdekel?

16 chipselecte van rákötve egy spi busznak 2db 595 re 500khzn megy kb és az összes spi szenzor egy bmo85 spi módban ás a lehető leggyorsabban akarom lekérdezni mind a 16 bnot

Tisztán és hatékonyan szeretnél 16 SPI-eszközt (16× BME/BMO85 szenzort) lekérdezni 1 SPI buszon, külön CS (chip select) lábbal mindegyiknek, és két darab 74HC595 shift regiszteren keresztül vezérled a CS-ket. Az SPI sebesség jelenleg ~500 kHz, és cél a minél gyorsabb, sorban lekérdezés.
🚀 Célod:

Lekérdezni a 16 szenzort a lehető leggyorsabban, úgy hogy az SPI busz közös, csak a CS-t multiplexeled.

## ✅ Alapfelállás

### 1 SPI busz 16 eszköz (BMO/BME85 SPI mód)

2 × 74HC595 = 16 bit = 16 chip select
A 74HC595 vezérli a CS biteket, és a CS csak az éppen kiválasztott eszköznél legyen LOW. SPI órajel: kb. 500 kHz

## ⚠️ A szűk keresztmetszet: 595 shiftelés sebessége

A 595-t 16 biten shiftelsz minden eszközhöz, tehát minden BME85 lekérdezéshez 2 byte-ot kell shiftelni a CS miatt, mielőtt egyáltalán SPI tranzakciót indítanál.
Ez nagyon fontos: ha bitbanginggal shiftelsz (~10-100 kHz shiftsebesség), akkor a 595 frissítési idő dominálni fog.

## 💡 Megoldás: Gyors CS frissítés hardveres SPI-vel

- Lépések:

### 1. Használj egy másik SPI perifériát a 595 vezérlésére

Pl. SPI1 vagy SPI2 (ESP32S3-n több SPI periféria van). SPI-n shifteld ki a 2 byte-os CS mintát a 74HC595-nek.
Printed using ChatGPT to PDF, (https://pdfcrowd.com/chatgpt-to-pdf/?ref=chatgpt) powered by PDFCrowd HTML to PDF API. (https://pdfcrowd.com/api/html-to-pdf-api/?ref=chatgpt) | 8/27

### 2. Használj két külön SPIClass-t:

SPI → a szenzorokhoz
SPI_CS → a 74HC595 vezérléséhez

## 🔄 CS váltás logika

cpp

void selectSensor(uint8_t sensorIndex) {
uint16_t csData = ~(1 << sensorIndex); // Aktív LOW
digitalWrite(latchPin, LOW);
SPI_CS.beginTransaction(SPISettings(10000000, MSBFIRST, SPI_MODE0)); // 10 MHz SPI_CS.transfer(csData >> 8);
SPI_CS.transfer(csData & 0xFF);
SPI_CS.endTransaction();
digitalWrite(latchPin, HIGH);
}

Ez a kód 595-be shifteli be a kiválasztott szenzor CS-jét.
A ~1–2 µs alatt frissíted a 595-t hardver SPI-vel.

## 🧪 Teljes ciklus: időráfordítás becslés

Művelet | Idő (becslés)
74HC595 shift (SPI-n) | ~1–2 µs
SPI szenzor olvasás | ~100–300 µs (attól függ, mit kérdezel le)
Késleltetés / egyéb | minimalizálva
Összesen / szenzor | ~200–500 µs
Összesen / 16 szenzor | ~3–8 ms
✅ Tehát egy teljes ciklus alatt akár 125–300 Hz frissítési gyakoriságot érhetsz el az összes szenzorra együtt, ha optimalizálsz.

## 🔧 Extra optimalizálások

Használj DMA-s SPI olvasást, ha lehet – különösen ESP-IDF-ben.
Ne kapcsold le a CS minden regiszter után: ha tudod, hogy mindig 1 aktív van, csak shifteld be a következőt.
Használhatsz ring buffer-szerű CS maszkolást (előre beállított CS byte tömb).
Ne várj szenzor konverzióra, ha nem szükséges (pl. forced mode helyett continuous).

## 🎯 Összefoglalás

✅ Igen, lehet gyorsan és hatékonyan vezérelni 16 SPI szenzort egy SPI buszon, 74HC595-t használva CS-multiplexelésre, ha:

Printed using ChatGPT to PDF, (https://pdfcrowd.com/chatgpt-to-pdf/?ref=chatgpt) powered by PDFCrowd HTML to PDF API. (https://pdfcrowd.com/api/html-to-pdf-api/?ref=chatgpt) | 9/27

Fontos | Részlet
SPI-vel shiftelsz 595-be | Ne bitbanging
Két SPI periféria | 1 a szenzoroknak, 1 a CS-nek
Aktív LOW CS logika | csak 1 bit legyen 0 a 16-ból
Gyors SPI beállítások | 10 MHz SPI sebesség 595-höz és 1–2 MHz a szenzorokhoz
Ha akarod, írok egy teljes példaprogramot ESP32-S3-ra, ami ezt csinálja. Érdekel?

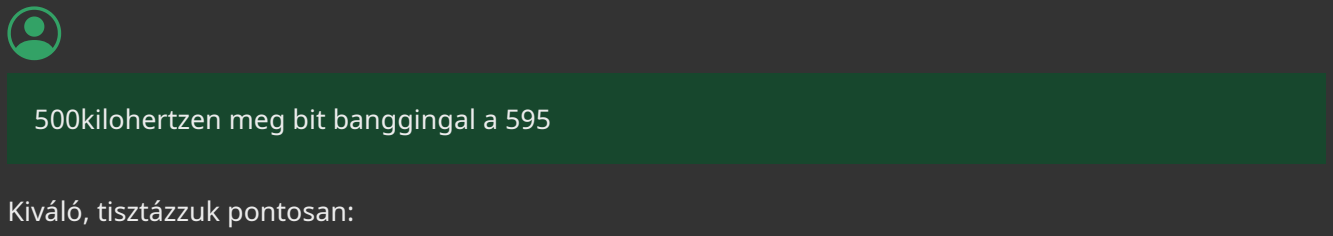
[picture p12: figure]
500kilohertzen meg bit banggingal a 595; Kiváló, tisztázzuk pontosan:

🧠 Ha 74HC595-öt bitbanginggal vezérled ESP32-S3-on, és kb. 500 kHz-es frissítési sebességet mérsz, akkor mit jelent ez?

## 🎯 Rövid válasz:

Igen, az teljesen reális.
Bitbanging módszerrel egy ESP32-S3 képes kb. 500 kHz körüli órajellel kiírni a biteket egy 74HC595-re digitális GPIO műveletekkel (ha a digitalWrite() helyett gyorsabb módszert használsz – pl.
gpio_set_level() vagy GPIO.out_w1ts / w1tc).

## 📊 Mit jelent az 500 kHz a 595 vezérlésénél?

500 kHz SPI clock = 1 bit minden 2 µs

### 16 bit shiftelése = 16 × 2 µs = 32 µs egy teljes CS frissítésre (2 byte a 595-be)

Ez azt jelenti, hogy egy új CS állapot beállítása ~32 µs, amivel akár 30.000 chip select frissítést másodpercenként is tudsz csinálni, ha csak ezt csinálod.

## ⏱️ Reális számok bitbanging esetén (ESP32-n)

### 1. Ha digitalWrite()-et használsz

### 1 bit shift = ~5–8 µs 16 bit shift = 80–130 µs

= kb. ~100–200 kHz maximum (nem 500 kHz)

### 2. Ha gyors GPIO (pl. gpio_set_level() vagy GPIO.out_w1ts)

### 1 bit shift = ~1–2 µs 16 bit = 16–32 µs

Printed using ChatGPT to PDF, (https://pdfcrowd.com/chatgpt-to-pdf/?ref=chatgpt) powered by PDFCrowd HTML to PDF API. (https://pdfcrowd.com/api/html-to-pdf-api/?ref=chatgpt) | 10/27

= ~500 kHz vagy akár 1 MHz shiftelés is elérhető

Ez alapján:
✅ Ha 500 kHz-et mértél, akkor nem sima digitalWrite()-tel csinálod, hanem valamilyen gyorsabb port-művelettel (pl. direkt regiszterírás vagy esp-idf gpio_set_level()).

## 🧪 Teszt: 500 kHz bitbanging tempó

Példa direkt GPIO shiftelésre ESP32-n (bitbang SPI a 595-höz):

cpp

#define DATA_PIN 11

#define CLOCK_PIN 12

#define LATCH_PIN 10

void shiftOut595(uint16_t data) {
for (int i = 15; i >= 0; i--) { gpio_set_level(CLOCK_PIN, 0); gpio_set_level(DATA_PIN, (data >> i) & 0x01); gpio_set_level(CLOCK_PIN, 1);
}
}

Ez így mehet 500 kHz+ sebességgel, különösen ha az gpio_set_level()-t inline regiszter írásra cseréled (GPIO.out_w1ts / w1tc), ami még gyorsabb.

## 🧠 Megerősítés:

Ha a te rendszeredben bitbanginggal 500 kHz-et mérsz 74HC595 kimeneten:

✔️ Az teljesen reális, ha gyors GPIO-vezérlést használsz
❌ Nem reális, ha sima digitalWrite() a kimenetvezérlés

## 🚀 Mit érdemes csinálni?

Ha már így is 500 kHz-en megy a 595, akkor:

Használd bátran a 16 CS vonalhoz!
Ne is bonyolítsd feltétlenül SPI-vel, ha ez a tempó neked elég.
A teljes szenzorolvasási időt inkább a BME/BMO85 válaszideje fogja meghatározni, nem a CS shiftelés sebessége.

Ha szeretnéd, tudok példát adni:

shiftOut() gyorsabb, regiszter-alapú verziójára
vagy teljes 16 szenzoros SPI multiplexelésre 74HC595-tel.

Szólj, melyik érdekel!
Printed using ChatGPT to PDF, (https://pdfcrowd.com/chatgpt-to-pdf/?ref=chatgpt) powered by PDFCrowd HTML to PDF API. (https://pdfcrowd.com/api/html-to-pdf-api/?ref=chatgpt) | 11/27

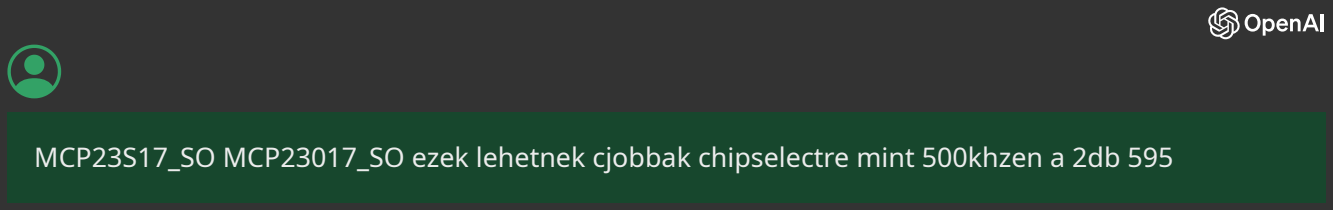
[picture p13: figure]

MCP23S17_SO MCP23017_SO ezek lehetnek cjobbak chipselectre mint 500khzen a 2db 595

🧠 Igen, az MCP23S17 (SPI-s I/O expander) sok szempontból jobb lehet CS-multiplexelésre, mint 2 db 74HC595 bitbanginggal 500 kHz-en. Nézzük összehasonlítva!

## 🥊 74HC595 vs MCP23S17 (vagy I²C-s MCP23017)

Tulajdonság | 74HC595 (bitbang) | MCP23S17 (SPI) | MCP23017 (I²C)
Busz | Bitbang GPIO | SPI | I²C
Frissítési seb. | ~500 kHz | akár 10 MHz SPI | ~100–400 kHz I²C
Regiszterelérés | Nincs – csak shift | I/O port regiszterek | Ugyanaz mint SPI-s verzió
Parancs hossz | 2 byte fix | ~3 byte SPI parancs | ~3–5 byte I²C parancs
Állapotolvasás | Nincs (write-only) | Lehetséges | Lehetséges
Stabilitás | Nincs latch (külső) | Belső regiszter + IRQ | Lassabb, de stabil
GPIO állapot | Nincs megtartva | Megőrzi, olvasható | Megőrzi, olvasható
Áramfogyasztás | alacsony | alacsony | alacsony

## ✅ Előnyök MCP23S17 használatával

1. 🎯 Stabil és megbízható CS vezérlés

Nem kell újra shiftelni minden szenzorhoz: csak egy portot írsz, és a többi bit változatlan marad. Ez óriási előny: nem kell minden szenzorciklusnál 16 bitet shiftelni.
2. ⚡ Gyors SPI hozzáférés

SPI buszon mehet akár 10 MHz sebességgel → portírás <1 µs alatt is lehet. Az MCP23S17 gyorsabb, mint bitbanged 74HC595.
3. 🧠 Tartja az állapotot

A kimenetek megtartják a beállított szinteket.
A 74HC595 minden frissítésnél teljes új shiftelést igényel.
4. ️ Egyszerűbb kód

Egy writeGPIO(register, value) művelettel vezérled a 16 CS vonalat.

## ❌ Hátrányok

Printed using ChatGPT to PDF, (https://pdfcrowd.com/chatgpt-to-pdf/?ref=chatgpt) powered by PDFCrowd HTML to PDF API. (https://pdfcrowd.com/api/html-to-pdf-api/?ref=chatgpt) | 12/27

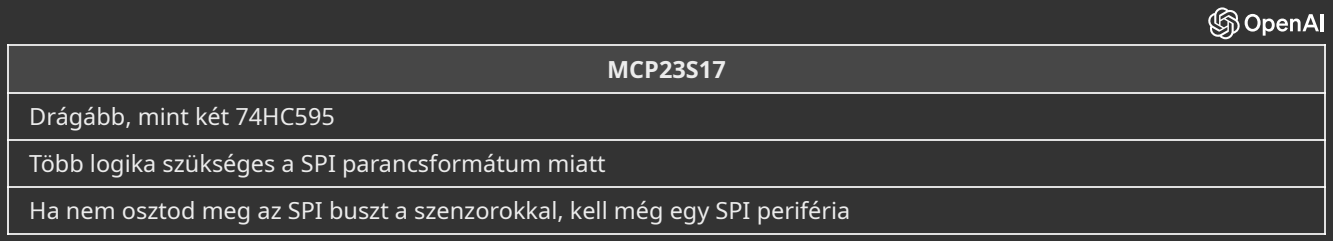
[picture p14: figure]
MCP23S17; Drágább, mint két 74HC595

Több logika szükséges a SPI parancsformátum miatt
Ha nem osztod meg az SPI buszt a szenzorokkal, kell még egy SPI periféria

## ⚠️ Figyelem a SPI csatornákra

Ha a BME85 szenzoraid és az MCP23S17 ugyanazon az SPI buszon vannak, figyelj a következőkre:

Ha nem használsz külön CS MCP23S17-nek, minden szenzor CS-váltásához először az MCP23S17-re kell SPI-t küldeni, utána a BME85-nek.
Ez megnöveli a teljes ciklusidőt.

📌 Ideális, ha van egy külön SPI perifériád az MCP23S17-nek – pl. SPI2 az ESP32S3-n.

## 🧪 Időmérés példa

1. 74HC595 bitbang (~500 kHz):

### 2 byte shift → ~32 µs

### 2. MCP23S17 SPI (10 MHz):

SPI parancs 3 byte = 24 bit @ 10 MHz = 2.4 µs
kevés szoftver overhead
⏱️ Valós frissítés ideje: ~5 µs

✅ Tehát ~6–7× gyorsabb lehet CS váltás, és egyszerűbb kezelni a biteket.

## ✅ Összefoglalás: Érdemes MCP23S17-et használni?

Szempont | Értékelés
Sebesség | 🟢 Jobb (akár 2–5 µs CS váltás)
Kód egyszerűsége | 🟢 Jobb (bitmanipuláció regiszteren)
Hardver bonyolultság | 🟡 Kicsit nő (SPI parancskezelés)
Költség / elérhetőség | 🔴 Rosszabb, mint 74HC595
✅ Ha fontos a sebesség és megbízhatóság, az MCP23S17 jobb választás CS vezérlésre, mint 2db 595 bitbangingal.

🎁 Szívesen írok példát ESP32-S3-hoz MCP23S17 kezelésére chipselectként – csak szólj!

Printed using ChatGPT to PDF, (https://pdfcrowd.com/chatgpt-to-pdf/?ref=chatgpt) powered by PDFCrowd HTML to PDF API. (https://pdfcrowd.com/api/html-to-pdf-api/?ref=chatgpt) | 13/27

készíts pontos sebességtáblázatot hogy az spios verziója a 16bno val eg buszon van 8 mhzn és a

Rendben! Itt van egy részletes összehasonlító táblázat a három lehetséges I/O bővítő megoldásról –

### 16 chip select (CS) vonal vezérlésére:

MCP23S17 (SPI-s) – SPI buszon
MCP23017 (I²C-s) – I²C buszon
2 × 74HC595 – Bitbanged shift regiszter

## ⚙️ Konfigurációs paraméterek (alapfeltételezések):

Paraméter | Érték
CS vonalak száma | 16
SPI órajel (MCP23S17) | 8 MHz
I²C órajel (MCP23017) | 400 kHz (Fast Mode)
Bitbang 595 órajel | 500 kHz
SPI írási parancs MCP23S17 | 3 byte (24 bit)
I²C írási parancs MCP23017 | 5 byte (40 bit)
595 shiftelés | 2 byte (16 bit)

## 📊 Sebességtáblázat – 1 CS váltás ideje (átlagosan)

Módszer | Busz | Órajel | Adatmennyiség | Idő (csak buszon) | Valós frissítés (becslés)
MCP23S17 | SPI | 8 MHz | 3 byte (24 bit) | 3.0 µs | ~5–6 µs (overheaddel)
MCP23017 | I²C | 400 kHz | 5 byte (40 bit) | 100 µs | ~120–150 µs (ACK, stb.)
2 × 74HC595 | Bitbanged | 500 kHz | 2 byte (16 bit) | 32 µs | ~35–40 µs (software overhead)

## ⏱️ Sebesség – 16 CS váltás teljes ideje (szenzor-polling kör)

Tegyük fel, hogy mind a 16 CS-t külön-külön aktiválod, és minden váltás előtt frissíted a 16 bites kimenetet.

Módszer | 1 váltás ideje | 16 váltás ideje
MCP23S17 | ~6 µs | ~96 µs
MCP23017 | ~120 µs | ~1920 µs
74HC595 | ~35 µs | ~560 µs
Printed using ChatGPT to PDF, (https://pdfcrowd.com/chatgpt-to-pdf/?ref=chatgpt) powered by PDFCrowd HTML to PDF API. (https://pdfcrowd.com/api/html-to-pdf-api/?ref=chatgpt) | 14/27

## ✅ Sebesség konklúzió (csak CS váltás):

Rang | Módszer | Előny
🥇 1 | MCP23S17 SPI | Leggyorsabb és stabil
🥈 2 | 74HC595 @500kHz | Egyszerűbb, de lassabb
🥉 3 | MCP23017 I²C | Lassú, nem ideális CS-hez

## 💡 Megjegyzések

MCP23S17 (SPI):
Stabil, megbízható, kiváló 16 GPIO gyors vezérléséhez.
Használható bármilyen GPIO-multiplexelésre, nem csak CS-re.
74HC595:
Jó alternatíva, ha nincs szabad SPI perifériád, vagy fontos a filléres megoldás. Bitbanging miatt a CPU-t terheli.
MCP23017 (I²C):
Egyszerű implementáció, de túl lassú aktív SPI CS vezérléshez.
Inkább LED vagy gombolvasásra való.

## 🎁 Ha érdekel:

Tudok adni ESP32S3-re példát:

MCP23S17 kezelésre SPI-n
Gyors shiftOut 595-höz
Optimalizált CS váltásra

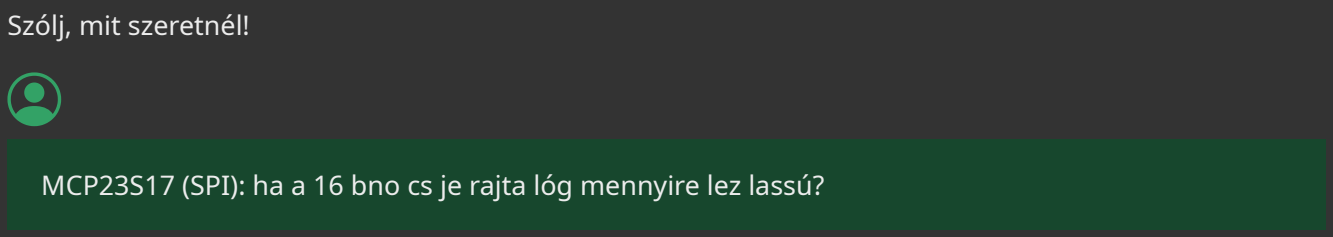
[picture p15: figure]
Szólj, mit szeretnél!

MCP23S17 (SPI): ha a 16 bno cs je rajta lóg mennyire lez lassú?

Nagyon jó kérdés! Itt most kifejezetten azt nézzük meg, mi történik, ha az összes 16 chip select (CS) vonalat egy MCP23S17 vezérli SPI-n keresztül, és minden SPI-szenzort (pl. BME85) gyorsan, sorban szeretnél lekérdezni.

## 🔍 Mi történik egy CS váltásnál MCP23S17-tel?

A MCP23S17 egy SPI-s I/O expander, tehát:

Printed using ChatGPT to PDF, (https://pdfcrowd.com/chatgpt-to-pdf/?ref=chatgpt) powered by PDFCrowd HTML to PDF API. (https://pdfcrowd.com/api/html-to-pdf-api/?ref=chatgpt) | 15/27

A CS-k kimenetek, egy 16 bites regiszter (GPIOA, GPIOB) értékét módosítva vezérled őket. Minden CS-váltás egy SPI tranzakció, ami:

### 3 bájtos SPI parancs:

[OPCODE][REG_ADDR][DATA]
Ha csak 1 bitet változtatsz, akkor is a teljes 8 bitet (vagy akár 16 bitet) ki kell küldeni.

## ⏱️ Sebességszámítás 16 külön CS-váltásra (16 szenzor lekérdezéséhez)

📐 Paraméterek:

SPI órajel: 8 MHz
Parancshossz: 3 byte (24 bit)

### 1 váltás ideje SPI-n:

👉 Reálisan (kódfuttatással, SPI megindítással, loop overheaddel együtt): ~5–6 µs / CS váltás

⚠️ És ha 16 szenzort akarsz végigpollolni?

Minden szenzornál ez történik:

### 1. MCP23S17-nel kikapcsolod az előző CS-t + bekapcsolod az aktuális CS-t →

új GPIO értéket írsz → 1 SPI tranzakció

### 2. Ezután jön a szenzor SPI kommunikáció

🧮 MCP23S17 összes CS-váltási ideje (16 eszköz)

Művelet | Idő (kb.)
1 váltás (1 CS állítással) | ~6 µs
16 váltás (külön CS minden szenzornak) | ~96 µs

## 🚀 Összesített ciklusidő – teljes szenzorkiolvasás (becslés)

Tegyük fel:

BME85 SPI olvasás ideje ~100–200 µs / darab (pl. nyomás, hőmérséklet együtt)

### 16 darab szenzor van

Teljes ciklusidő becslés:

### 8 MHz =

24 bit | 3.0 μs
Printed using ChatGPT to PDF, (https://pdfcrowd.com/chatgpt-to-pdf/?ref=chatgpt) powered by PDFCrowd HTML to PDF API. (https://pdfcrowd.com/api/html-to-pdf-api/?ref=chatgpt) | 16/27

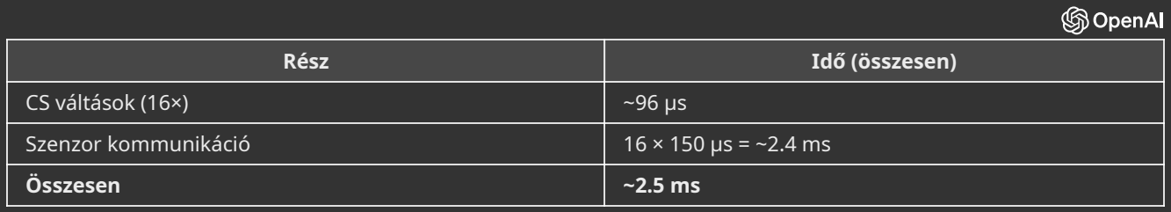
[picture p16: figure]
Rész; Idő (összesen); CS váltások (16×); Összesen

Szenzor kommunikáció | 16 × 150 µs = ~2.4 ms

➡️ Tehát a CS-váltás a teljes ciklusidő kevesebb mint 5%-a!

## ✅ Következtetés:

Az MCP23S17 SPI-n, 8 MHz SPI sebességnél:

16 külön CS vonal vezérlése teljesen reálisan és gyorsan kivitelezhető.
Nem szűk keresztmetszet – a szenzor SPI kiolvasás sokkal tovább tart, mint a CS-váltás.

## 🟢 Ha a célod:

### 16 SPI-s BME85 (vagy más) szenzor gyors lekérdezése

Minimális CPU terhelés
Stabil CS-vezérlés (nem shifteléssel)

👉 Az MCP23S17 kiváló megoldás.
Ha érdekel, adok minta ESP32-S3 kódot hozzá is!

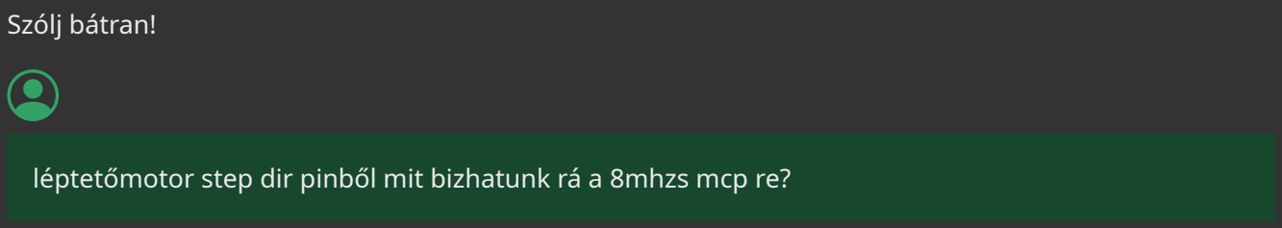
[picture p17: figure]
Szólj bátran!

léptetőmotor step dir pinből mit bizhatunk rá a 8mhzs mcp re?

Oké, szóval léptetőmotor step/dir vezérlését szeretnéd megoldani az MCP23S17 SPI I/O expanderrel, ami 8 MHz-en megy — és az a kérdés, hogy mennyire megbízható, gyors lesz ez a megoldás?

## 🤔 Mi a helyzet a léptetőmotor step/dir jellel?

Step pin: impulzusokat kell kapjon a léptetőmotor driver, az impulzusok száma határozza meg a lépések számát.
Dir pin: irányjelzés, általában kevésbé gyorsan változik, csak amikor irányt váltasz.

## ⚡ Mennyi a delay, ha MCP23S17-ről küldesz impulzust 8 MHz SPI-vel?

Működési alap:

Printed using ChatGPT to PDF, (https://pdfcrowd.com/chatgpt-to-pdf/?ref=chatgpt) powered by PDFCrowd HTML to PDF API. (https://pdfcrowd.com/api/html-to-pdf-api/?ref=chatgpt) | 17/27

Az MCP23S17 nem tud önállóan generálni impulzust, csak állapotot vált a kimeneten, amit SPI-vel kell írnunk.
Egy impulzus létrehozásához legalább két írás szükséges:
Step pin magasra állítása
Step pin alacsonyra állítása
Időigény:

Egy SPI írás (3 byte) 8 MHz-en kb. 3 µs (átvitel).
Szoftver overhead-del együtt kb. 5-6 µs / írás.
Impulzus létrehozásához 2×5-6 µs = 10-12 µs szükséges minimum (ha optimálisan van megírva a kód).

## ⏳ Ez milyen léptetési sebességnek felel meg?

Maximális impulzus frekvencia

Ez az elméleti maximum, valós környezetben (CPU terhelés, busz többi forgalma) inkább 50-70 kHz körüli stabil frekvenciára számíts.

## ‍♂️ Megbízhatóság?

Az MCP23S17 jó megoldás alacsony és közepes frekvenciás step/dir vezérlésre (néhány tízezer lépés/sec).
Profibb léptetőmotorvezérléshez (pl. >100 kHz step freq) inkább dedikált, hardveres PWM vagy mikrovezérlő direkt GPIO-k kellenek.
Az MCP23S17 buszon osztozik más SPI eszközökkel, ez plusz késleltetést jelenthet.

## 🔑 Összegzés

Paraméter | Érték, tapasztalat
Minimális impulzus idő | ~10-12 µs (2× SPI írás @8 MHz)
Max step frekvencia | kb. 70-80 kHz (elmélet, valós kb. 50 kHz)
Dir pin sebesség | Alacsony, bármekkora jó
Megbízhatóság | Jó közepes sebességnél
Jobb megoldás | Mikrovezérlő GPIO vagy dedikált stepper driver

Ha a léptetőmotorod nem igényel nagyon nagy sebességet (pl. max 30-40 kHz step impulzus, ami sok motorhoz bőven elég), akkor az MCP23S17-zel is működhet a step/dir jel.
Ha viszont nagyobb frekvenciára van szükséged, vagy nagyon pontos impulzusokat, akkor érdemes más megoldást keresni.
fmax = | ≈ impulzusido\H

1
12

1
μs ≈ 83kHz
Printed using ChatGPT to PDF, (https://pdfcrowd.com/chatgpt-to-pdf/?ref=chatgpt) powered by PDFCrowd HTML to PDF API. (https://pdfcrowd.com/api/html-to-pdf-api/?ref=chatgpt) | 18/27

Ha kell, segítek akár a MCP23S17-es step/dir kód mintával vagy alternatívák keresésével is!

Igen, pontosan! A DIR (irány) jelet nyugodtan átpakolhatod az MCP23S17-re, mert az irányváltás nem időkritikus, és nem kell milliószor másodpercenként változnia. Nézzük konkrétan, mit bír el:

## ✅ DIR pin vezérlés MCP23S17-ről – teljesen oké

Miért jó az MCP-re a DIR pin?

Az irányt általában csak lépésirány váltás előtt állítod be.
Nem kell 100 kHz-cel váltogatni.
Egy SPI írás 6 µs → teljesen jó ilyen ritka jelváltáshoz.
Ráadásul: akár több motor irányát is tudod egyszerre állítani, egyetlen 16 bites SPI írással.

## ❌ STEP pin → nem ajánlott MCP-re

Impulzust kell adni: magas → alacsony
Legalább 2 SPI írás → túl sok overhead
Kicsi az időzítési pontosság
Csak ~50–70 kHz-es step frekvencia érhető el → lassabb motorvezérlés

## ⚙️ Ajánlott kombináció léptetőmotorhoz:

Jel | Hova kösd? | Miért?
STEP | ESP32 GPIO | Precíz, gyors, akár PWM generálás
DIR | MCP23S17 kimenet | Stabil, ritkán vált, nem időkritikus

## ️ Alternatíva:

Az ESP32 támogatja RMT és LEDC perifériákat, amik hardveresen tudnak PWM jelet generálni – tökéletesek STEP impulzushoz.

Ha kéred, adok:

példát arra, hogyan állíts be DIR-t MCP23S17-en
és hogyan generálj STEP jelet hardveresen ESP32-n
Printed using ChatGPT to PDF, (https://pdfcrowd.com/chatgpt-to-pdf/?ref=chatgpt) powered by PDFCrowd HTML to PDF API. (https://pdfcrowd.com/api/html-to-pdf-api/?ref=chatgpt) | 19/27

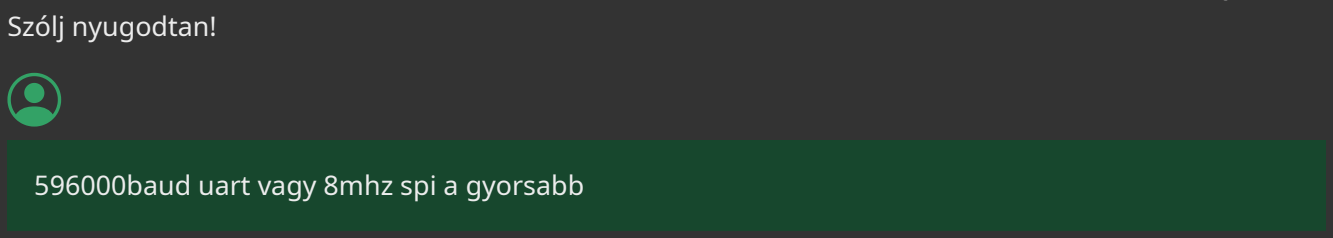
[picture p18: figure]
Szólj nyugodtan!

596000baud uart vagy 8mhz spi a gyorsabb

Remek kérdés! Nézzük meg pontosan, melyik gyorsabb: 596 000 baud UART vagy 8 MHz SPI, ha adatátvitel sebessége a lényeg.

## 📊 Összehasonlítás – UART vs. SPI sebesség (elmélet + gyakorlat)

Protokoll | Névleges sebesség | Nettó hasznos adat (8n1) | Átviteli sebesség | Megjegyzés
UART | 596 000 baud | 8 adatbit + 1 start + 1 stop → 10 bit / bájt | 59.6 kB/s | Szinkronizálatlan, soros
SPI | 8 MHz | 8 bit / bájt, teljes sávszél használható | 1 MB/s | Szinkron, órajelvezérelt

## 🧮 Számítási alap:

UART (596000 baud, 8N1):

### 1 byte = 10 bit

596 000 bit/s ÷ 10 = 59 600 byte/s (≈ 58.2 KiB/s) SPI (8 MHz, 8 bit):

### 1 byte = 8 bit

8 000 000 bit/s ÷ 8 = 1 000 000 byte/s (≈ 976.6 KiB/s)

## 🚀 SPI kb. 16× gyorsabb

8 MHz SPI sokkal gyorsabb, kb. 16–17-szer gyorsabb, mint 596 000 baud UART. A különbség még nagyobb, ha:

SPI master te vagy (pl. ESP32), és gyorsan tudod kezelni az adatokat nincs túl sok overhead vagy várakozás a perifériák részéről

## 🧪 Gyakorlatban számít:

UART-nál nagyobb eséllyel vannak bufferelési késleltetések, zajérzékenység
SPI sokkal stabilabb, ha nagy mennyiségű adatot kell átküldeni gyorsan
Printed using ChatGPT to PDF, (https://pdfcrowd.com/chatgpt-to-pdf/?ref=chatgpt) powered by PDFCrowd HTML to PDF API. (https://pdfcrowd.com/api/html-to-pdf-api/?ref=chatgpt) | 20/27

## ✅ Összegzés:

Metrika | UART @ 596 000 baud | SPI @ 8 MHz
Maximális sebesség | ~59.6 kB/s | ~1 MB/s
Stabilitás | Jó, de lassabb | Nagyon jó, gyorsabb
Időzítés | Laza (szinkronizálatlan) | Precíz (szinkron)
👉 SPI messze gyorsabb és megbízhatóbb, ha te vezérled az adatcserét.
Ha mondod, mit szeretnél átküldeni (pl. képet, szenzort, adatblokk), tudok javasolni optimális csatornát!

MCP23S17_SO ben ha egy regisztert akarok módosítani akkor az összes tartalmát ki kell küldenem?

Nagyon jó és fontos kérdés — főleg ha teljesítményt, sebességet vagy több kimenet vezérlését optimalizálod az MCP23S17 (SPI-s I/O expander) esetén.

## 🔧 Rövid válasz:

Nem, nem kell az összes tartalmát kiküldened, de egész bájtot (vagy bájtokat) mindig ki kell írnod, nem tudsz csak egyetlen bitet módosítani közvetlenül.

## 🧠 Részletesen: hogyan működik az írás?

Az MCP23S17 működése SPI-n keresztül így néz ki:
📦 Egy írási tranzakció formátuma (3 byte):

css

[ OPCODE | REG_ADDR | DATA ]

OPCODE → 0b0100[A2][A1][A0][R/W]
REG_ADDR → pl. 0x12 (GPIOA) vagy 0x14 (OLATA)
DATA → a teljes 8 bites érték, amit az adott regiszterbe írsz

## ❗ Ezért fontos:

Ha te például csak 1 bitet akarsz felhúzni vagy lehúzni egy kimeneten, akkor:

Előbb ki kell olvasnod a teljes 8 bites regisztert (GPIOA, OLATA stb.)
Bitművelettel módosítod a kívánt bitet (pl. | vagy &~)
Ezután visszaírod az egész 8 bitet SPI-n
Printed using ChatGPT to PDF, (https://pdfcrowd.com/chatgpt-to-pdf/?ref=chatgpt) powered by PDFCrowd HTML to PDF API. (https://pdfcrowd.com/api/html-to-pdf-api/?ref=chatgpt) | 21/27

Példa (1. lépés: olvasás):

cpp

uint8_t current = readRegister(GPIOA);

(2. lépés: módosítás, pl. a 3. bitet felhúzod):

cpp

current |= (1 << 3);

(3. lépés: visszaírás):

cpp

writeRegister(GPIOA, current);

## ⏱️ Időigény:

Olvasás: 3 byte SPI → ~3 µs (8 MHz-en)
Írás: 3 byte SPI → ~3 µs
Teljes művelet: kb. 6–10 µs, kódfuttatástól függően

## ️ Összegzés:

Művelet | Kell?
Az egész MCP tartalmat írni | ❌ Nem
Az adott regiszter egész bájtját írni | ✅ Igen
Egy bit módosításához olvasás + írás | ✅ Igen

👉 Ha gyakran módosítasz csak egy-egy bitet, érdemes egy lokális shadow másolatot (pl. uint8_t gpioA_shadow) fenntartani a kódban, így nem kell mindig olvasni a regisztert. Csak bitművelet, aztán visszaírás.
Ha szeretnél, írok hozzá kis példakódot is ESP32-höz!

Az A0, A1, A2 lábak az MCP23S17 SPI-s verziójánál (azaz az MCP23S17-SO, nem I2C!) hardveres címkiválasztásra szolgálnak, vagyis arra, hogy több MCP23S17 chipet is fel tudj tenni egy SPI buszra, és meg tudjad különböztetni őket szoftveresen.

Printed using ChatGPT to PDF, (https://pdfcrowd.com/chatgpt-to-pdf/?ref=chatgpt) powered by PDFCrowd HTML to PDF API. (https://pdfcrowd.com/api/html-to-pdf-api/?ref=chatgpt) | 22/27

## 🧠 Hogyan működik?

Az SPI kommunikációban az MCP23S17 OPCODE első byte-ja így néz ki:

0 1 0 0 A2 A1 A0 R/W

A2, A1, A0 a hardveresen beállított lábak értéke (0 vagy 1) R/W: 0 = írás, 1 = olvasás
Példa:

Ha A2=0, A1=1, A0=0 → akkor az eszközcím bitjei ezek lesznek:

0 1 0 0 0 1 0 0 = 0x44 (írás) vagy 0x45 (olvasás)

## ️ Mire használhatod?

SPI-n az eszközök chip selecttel vannak kiválasztva → ez már önmagában elég lenne.
DE: az MCP23S17 lehetővé teszi, hogy egy chip select alatt akár több MCP23S17 is legyen, külön A0–A2 beállítással megkülönböztetve őket.
Így 1 CS vonalon akár 8 MCP23S17 chipet is el tudsz különíteni!

## ✅ Használati lehetőségek:

A2 | A1 | A0 | OPCODE (írás) | OPCODE (olvasás)
0 | 0 | 0 | 0x40 | 0x41
0 | 0 | 1 | 0x42 | 0x43
0 | 1 | 0 | 0x44 | 0x45
0 | 1 | 1 | 0x46 | 0x47
1 | 0 | 0 | 0x48 | 0x49
1 | 0 | 1 | 0x4A | 0x4B
1 | 1 | 0 | 0x4C | 0x4D
1 | 1 | 1 | 0x4E | 0x4F

## 📌 Összegzés:

A0–A2 szerepe | Jelentés
Hardvercím bit | Az SPI OPCODE része (0x40–0x4F)
Printed using ChatGPT to PDF, (https://pdfcrowd.com/chatgpt-to-pdf/?ref=chatgpt) powered by PDFCrowd HTML to PDF API. (https://pdfcrowd.com/api/html-to-pdf-api/?ref=chatgpt) | 23/27

3 bit = 8 egyedi chip | Egy CS vonalon akár 8 MCP chip
A busz szoftveresen különbözteti meg őket az OPCODE-del

Ha viszont csak egy MCP23S17 chip van a buszon, és van külön chip select lábad, akkor mindhárom cím-lábat le is földelheted (A0=A1=A2=0), és az OPCODE mindig 0x40 (írás) vagy 0x41 (olvasás) lesz. Szólj, ha szeretnél példakódot több MCP23S17 SPI-n való használatára!

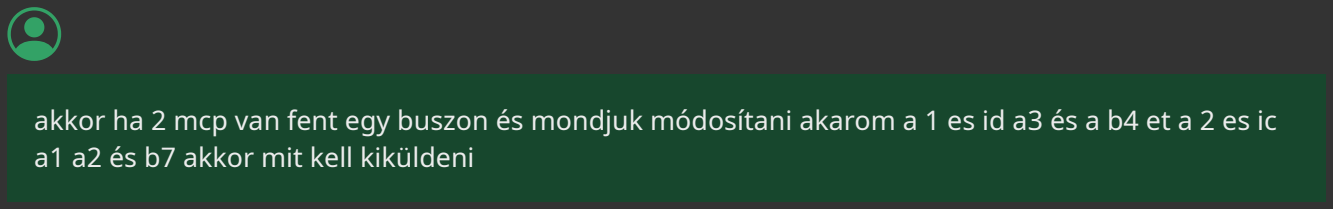
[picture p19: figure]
a1 a2 és b7 akkor mit kell kiküldeni

akkor ha 2 mcp van fent egy buszon és mondjuk módosítani akarom a 1 es id a3 és a b4 et a 2 es ic

Nagyon jó gyakorlati kérdés! Nézzük pontosan lépésről lépésre, milyen SPI üzenetet kell kiküldeni, ha két MCP23S17 van ugyanazon SPI buszon, és mindkettőn külön lábakat szeretnél állítani.

## 🧠 Kezdés: Címkiosztás

Tegyük fel:

MCP23S17 IC | A2 | A1 | A0 | OPCODE (írás)
Chip #1 | 0 | 0 | 1 | 0x42
Chip #2 | 0 | 1 | 0 | 0x44

(A0–A2 lábakat fizikai lábkötéssel állítod be, pl. GND vagy VCC)

## 🎯 Feladat:

MCP #1:

GPIOA3 = 1 (azaz IOCONA → A3)

GPIOB4 = 1 (azaz IOCONB → B4)
MCP #2:

GPIOA1 = 1

GPIOA2 = 1

GPIOB7 = 1
Tegyük fel, az összes GPIO-t kimenetnek állítottad be előre.

## ⚙️ MCP23S17 fontos regiszterek:

Printed using ChatGPT to PDF, (https://pdfcrowd.com/chatgpt-to-pdf/?ref=chatgpt) powered by PDFCrowd HTML to PDF API. (https://pdfcrowd.com/api/html-to-pdf-api/?ref=chatgpt) | 24/27

## 📤 SPI üzenetek:

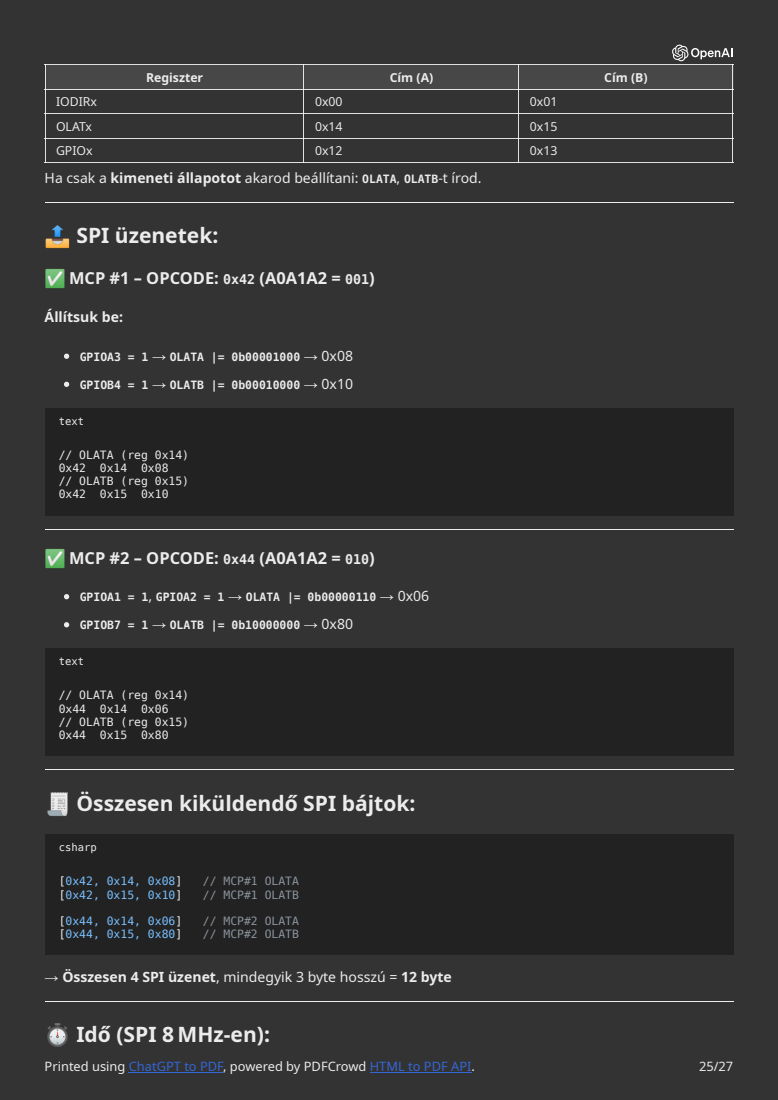
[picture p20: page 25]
✅ MCP #1 – OPCODE: 0x42 (A0A1A2 = 001); Állítsuk be:; GPIOA3 = 1 → OLATA |= 0b00001000 → 0x08; GPIOB4 = 1 → OLATB |= 0b00010000 → 0x10; text; // OLATA (reg 0x14) 0x42 0x14 0x08 // OLATB (reg 0x15) 0x42 0x15 0x10; ✅ MCP #2 – OPCODE: 0x44 (A0A1A2 = 010); GPIOA1 = 1, GPIOA2 = 1 → OLATA |= 0b00000110 → 0x06; GPIOB7 = 1 → OLATB |= 0b10000000 → 0x80; // OLATA (reg 0x14) 0x44 0x14 0x06 // OLATB (reg 0x15) 0x44 0x15 0x80; csharp; // MCP#1 OLATA; // MCP#1 OLATB; // MCP#2 OLATA; // MCP#2 OLATB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

Regiszter | Cím (A) | Cím (B)

IODIRx | 0x00 | 0x01
OLATx | 0x14 | 0x15
GPIOx | 0x12 | 0x13

Ha csak a kimeneti állapotot akarod beállítani: OLATA, OLATB-t írod.

🧾 Összesen kiküldendő SPI bájtok:

→ Összesen 4 SPI üzenet, mindegyik 3 byte hosszú = 12 byte
⏱️ Idő (SPI 8 MHz-en):

### 1 byte SPI → 1 µs → 12 byte → kb. 12 µs + minimális chip select overhead

## ⚠️ Tipp:

Ha csak bitet módosítasz, és nem tudod előre a többi értéket:

### 1. Előbb olvasd ki az OLAT regisztert 2. Módosítsd bitművelettel 3. Írd vissza → így más biteket nem írsz felül véletlenül

Ha szeretnéd, írok ehhez működő Arduino/ESP32 kódrészletet is!

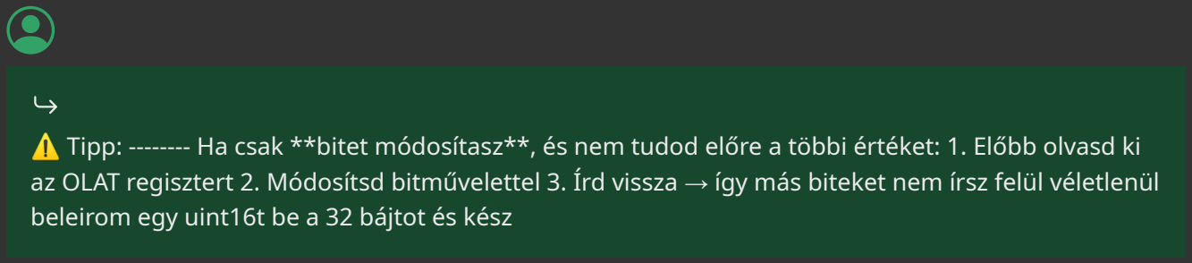
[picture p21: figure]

⚠️ Tipp: -------- Ha csak **bitet módosítasz**, és nem tudod előre a többi értéket: 1. Előbb olvasd ki az OLAT regisztert 2. Módosítsd bitművelettel 3. Írd vissza → így más biteket nem írsz felül véletlenül beleirom egy uint16t be a 32 bájtot és kész

Pontosan, ez egy nagyon jó megközelítés! Összefoglalva, ha több MCP23S17 kimeneti bitet szeretnél gyorsan és biztonságosan vezérelni, akkor:

## ✅ Megoldás: uint16_t változókkal shadow bufferként

Minden MCP23S17-hez fenntarthatsz egy uint16_t változót (16 bit → 8 bit port A + 8 bit port B) Bitműveletekkel ezt módosítod a kódban
Ha kell, akkor két uint8_t-ként kiküldöd SPI-n az OLATA, OLATB regiszterekbe

🧠 Példa:

cpp

// Shadow buffer 2 MCP-re
uint16_t mcp1_shadow = 0x0000;
uint16_t mcp2_shadow = 0x0000;

// Módosítunk egy bitet (pl. mcp1 - B4 = 1) mcp1_shadow |= (1 << (8 + 4)); // Port B4 -> bit 12

// mcp2 - A2 = 1
mcp2_shadow |= (1 << 2); // Port A2 -> bit 2

📤 Kiírás SPI-n (8MHz-en villámgyors):

Printed using ChatGPT to PDF, (https://pdfcrowd.com/chatgpt-to-pdf/?ref=chatgpt) powered by PDFCrowd HTML to PDF API. (https://pdfcrowd.com/api/html-to-pdf-api/?ref=chatgpt) | 26/27

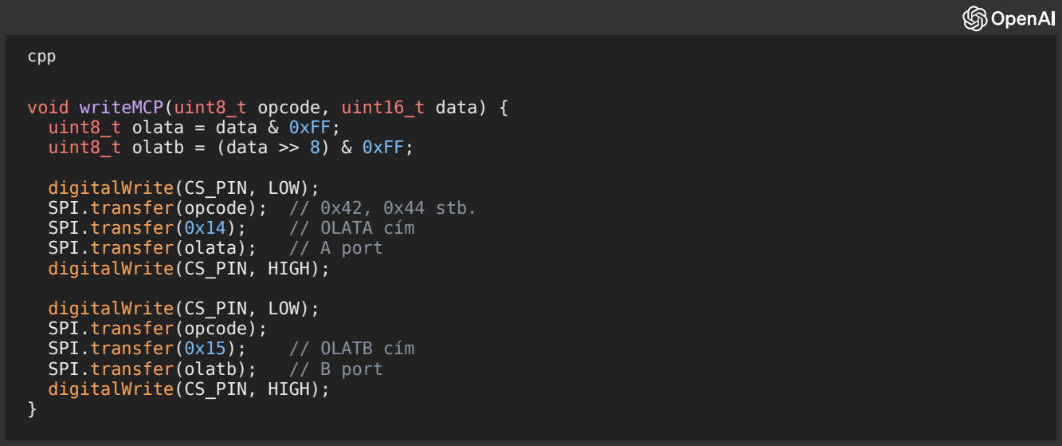
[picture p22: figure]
cpp; uint8_t olata = data & 0xFF; uint8_t olatb = (data >> 8) & 0xFF;; digitalWrite(CS_PIN, LOW); SPI.transfer(opcode); // 0x42, 0x44 stb.; SPI.transfer(0x14);; // OLATA cím; SPI.transfer(olata);; // A port; digitalWrite(CS_PIN, HIGH);; digitalWrite(CS_PIN, LOW); SPI.transfer(opcode);; SPI.transfer(0x15);; // OLATB cím; SPI.transfer(olatb);; // B port

void writeMCP(uint8_t opcode, uint16_t data) {

## ⚡ Előnyök:

Előny | Leírás
🧠 Egyszerű | Bitműveletek csak a uint16_t-n
💡 Átlátható | Nem kell mindig visszaolvasni a chipből
🚀 Gyors | SPI írás 6 byte/mcp ≈ 6 µs
✅ Stabil | Nincs véletlenül felülírt bit

## 📌 Összegzés:

Igen, ha shadow bufferként uint16_t-eket vezetsz minden MCP-re, akkor bármilyen kombinációban módosíthatsz bitet, és gyors, egyszerű, biztonságos az SPI kommunikáció. Ez az ipari módszer is. Ha szeretnél, adok teljes driver mintát ESP32-re 2 MCP23S17 kezelésére is.

Printed using ChatGPT to PDF, (https://pdfcrowd.com/chatgpt-to-pdf/?ref=chatgpt) powered by PDFCrowd HTML to PDF API. (https://pdfcrowd.com/api/html-to-pdf-api/?ref=chatgpt) | 27/27

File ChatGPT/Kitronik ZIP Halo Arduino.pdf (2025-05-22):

# Kitronik ZIP Halo Arduino

The Kitronik ZIP Halo is an accessory for the BBC micro:bit, not directly for Arduino. However, with some adaptation and additional components, it can be controlled by an Arduino since the ZIP Halo uses WS2812B addressable RGB LEDs (similar to NeoPixels), which are compatible with Arduino libraries.
What is the Kitronik ZIP Halo?

Shape: Circular ring with 24 addressable RGB LEDs.
Connector: It’s designed to fit around the micro:bit using its edge connector. LED Type: ZIP LEDs = WS2812B-compatible.

Can I use it with Arduino?

Yes, but with caveats:

You won’t use the micro:bit.
You will connect directly to the LED ring's power, ground, and data in pins. You must find and solder to the correct pins on the board.

How to wire ZIP Halo to Arduino

### 1. Power:

Connect 5V from Arduino to the ZIP Halo V+.
Connect GND from Arduino to ZIP Halo GND.

### 2. Data:

Connect a digital pin (e.g., D6) from Arduino to the ZIP Halo's DIN pin.

⚠️ Note: You may need to locate the correct data input pin on the ZIP Halo, which might involve checking its PCB traces or datasheet, since it doesn't have a standard pin header like NeoPixel rings.

Arduino Code Example

You can use the Adafruit NeoPixel library:

Printed using ChatGPT to PDF, (https://pdfcrowd.com/chatgpt-to-pdf/?ref=chatgpt) powered by PDFCrowd HTML to PDF API. (https://pdfcrowd.com/api/html-to-pdf-api/?ref=chatgpt) | 1/8

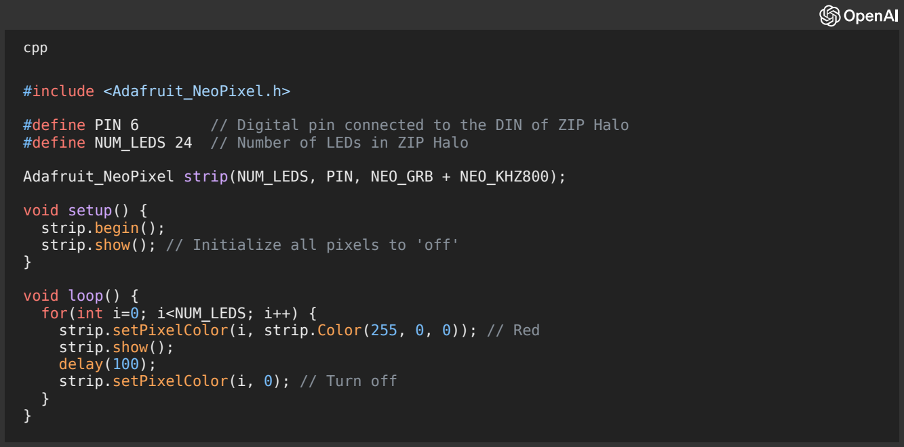
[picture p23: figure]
cpp; #include <Adafruit_NeoPixel.h>; void setup() { strip.begin();; void loop() { for(int i=0; i<NUM_LEDS; i++) {; strip.show(); delay(100); strip.setPixelColor(i, 0); // Turn off

#define PIN 6 | // Digital pin connected to the DIN of ZIP Halo

#define NUM_LEDS 24 // Number of LEDs in ZIP Halo

Adafruit_NeoPixel strip(NUM_LEDS, PIN, NEO_GRB + NEO_KHZ800);

strip.show(); // Initialize all pixels to 'off'

strip.setPixelColor(i, strip.Color(255, 0, 0)); // Red

Tips

If using an external 5V power supply (recommended for all 24 LEDs at full brightness), be sure to tie the grounds together.
You may need a resistor (~330Ω) between Arduino data pin and DIN, and a capacitor (1000µF) across the power supply to protect the LEDs.

Would you like a wiring diagram or help identifying the correct soldering points on the ZIP Halo?

Természetesen! Itt van a Kitronik ZIP Halo és Arduino használata magyarul:

## 🎯 Mi az a Kitronik ZIP Halo?

A Kitronik ZIP Halo egy 24 darab RGB LED-ből álló kör alakú panel, amit eredetileg a BBC micro:bit-hez terveztek.

LED-ek típusa: WS2812B-kompatibilis, ugyanaz, mint a NeoPixel.
Cél: Fényjátékok, effektek készítése.
Csatlakozás: Eredetileg micro:bit-re pattintható, de használható más mikrokontrollerrel is, például Arduinóval.

## ️ Használható-e Arduinóval?

Printed using ChatGPT to PDF, (https://pdfcrowd.com/chatgpt-to-pdf/?ref=chatgpt) powered by PDFCrowd HTML to PDF API. (https://pdfcrowd.com/api/html-to-pdf-api/?ref=chatgpt) | 2/8

Igen, használható, mivel a benne lévő LED-ek WS2812B (NeoPixel) típusúak, amiket az Arduino is tud vezérelni. Viszont:

Nem micro:bit-tel használod, hanem közvetlenül vezérled az Arduino-ról.
Forrasztásra lehet szükség, hogy elérd a LED-ek adatbemeneti (DIN) pontját.

## 🔌 Bekötés Arduino-hoz

Szükséges bekötések:

+5V (VCC) → Arduino 5V
GND → Arduino GND
DIN (Data In) → Arduino egy digitális lába, pl. D6

⚠️ Fontos: A ZIP Halo panelen meg kell keresned azt a pontot, ahol a DIN elérhető (mivel micro:bit-hez készült, nem szabványos tüskesorral van).

## 💡 Arduino példa kód

Használjuk az Adafruit NeoPixel könyvtárat (előbb telepítsd az Arduino IDE-ben).

cpp

#include <Adafruit_NeoPixel.h>

#define PIN 6 | // Ide kötöd a ZIP Halo adatbemenetét

#define NUM_LEDS 24 // A ZIP Halo LED-jeinek száma

Adafruit_NeoPixel strip(NUM_LEDS, PIN, NEO_GRB + NEO_KHZ800);

void setup() {
strip.begin();
strip.show(); // Kikapcsolja az összes LED-et
}

void loop() {
for(int i = 0; i < NUM_LEDS; i++) {
strip.setPixelColor(i, strip.Color(255, 0, 0)); // Piros szín strip.show();
delay(100);
strip.setPixelColor(i, 0); // Kikapcsolja az aktuális LED-et }
}

## 🧠 Tipp:

Ha külső tápellátást használsz (pl. 5V adapter), a GND-t össze kell kötni az Arduino GND-jével! Javasolt:
330 Ohm-os ellenállás az adatvezetékbe
1000 µF kondenzátor a tápellátás és GND közé
Printed using ChatGPT to PDF, (https://pdfcrowd.com/chatgpt-to-pdf/?ref=chatgpt) powered by PDFCrowd HTML to PDF API. (https://pdfcrowd.com/api/html-to-pdf-api/?ref=chatgpt) | 3/8

## 🔍 Segíthetek még?

Szükséged van egy bekötési rajzra?
Nem tudod, hova kell forrasztani a DIN vezetéket a ZIP Halo-n? Szeretnél színváltós vagy animált effekteket?

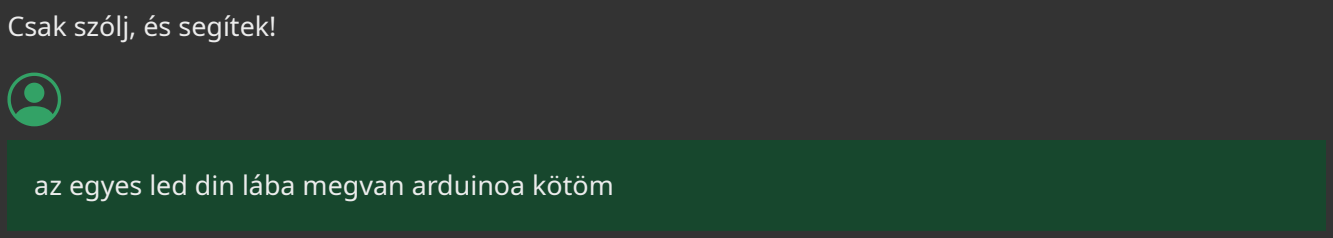
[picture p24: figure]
Csak szólj, és segítek!

az egyes led din lába megvan arduinoa kötöm

Szuper! Ha már megtaláltad az egyik LED DIN (adatbemeneti) lábát a ZIP Halo-n, akkor gyakorlatilag közvetlenül vezérelheted Arduino-ról, ugyanúgy, mint bármely más WS2812B (NeoPixel) LED-et.

## 🔌 Bekötés összefoglalva

ZIP Halo (vagy LED első bemeneti pontja) | Arduino lába
DIN (adat) | pl. D6
VCC / +5V | 5V
GND | GND

## ⚠️ Kiegészítő ajánlások

Ha biztosra akarsz menni:

Tedd be a DIN vonalba egy 330 Ohm-os ellenállást.
Tegyél egy 1000 µF / 6.3V vagy nagyobb kondenzátort a ZIP Halo táp +5V és GND közé (stabilizálja a feszültséget induláskor).

## ✅ Ellenőrző lista

### 1. Adatkábel jó helyre megy?

Arduino D6 → első LED DIN láb (irányra figyelj: Data In, ne Out).

### 2. Megfelelő feszültség?

WS2812 LED-ek 5V-on működnek a legjobban. Ha csak 3.3V van, a jelszint lehet problémás. Arduino UNO 5V-ot ad ki, azzal működni fog.

### 3. Könyvtár használat:

Az Arduino IDE-ben telepítsd: Adafruit NeoPixel Library

## 🧪 Tesztkód újra:

Printed using ChatGPT to PDF, (https://pdfcrowd.com/chatgpt-to-pdf/?ref=chatgpt) powered by PDFCrowd HTML to PDF API. (https://pdfcrowd.com/api/html-to-pdf-api/?ref=chatgpt) | 4/8

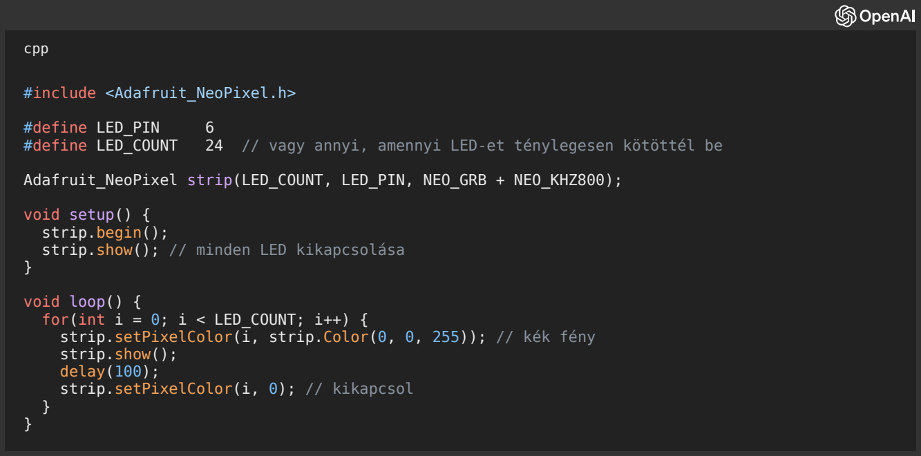
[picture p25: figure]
cpp; #include <Adafruit_NeoPixel.h>; #define LED_PIN; void setup() { strip.begin(); strip.show(); // minden LED kikapcsolása; void loop() { for(int i = 0; i < LED_COUNT; i++) {; strip.show(); delay(100); strip.setPixelColor(i, 0); // kikapcsol

#define LED_COUNT 24 // vagy annyi, amennyi LED-et ténylegesen kötöttél be

Adafruit_NeoPixel strip(LED_COUNT, LED_PIN, NEO_GRB + NEO_KHZ800);

strip.setPixelColor(i, strip.Color(0, 0, 255)); // kék fény

Ha nem világít:

Ellenőrizd a tápfeszültséget (multiméterrel).
Nézd meg, biztosan a Data In oldalhoz csatlakoztál.
Próbálj kevesebb LED-et beállítani (pl. 8), hátha nem az elsőt találta el a jelsorozat.

Szükség esetén küldhetsz képet a bekötésről, és segítek megnézni, jó-e.

Nagyszerű, hogy Wemos D1 Mini ESP32-t használsz! Az ESP32 tökéletes WS2812 (NeoPixel) LED-ek vezérlésére, de van néhány speciális figyelmeztetés, főleg ha a D1 lábra kötöd a DIN vezetéket a ZIP Halo-hoz.

## 📌 Összefoglaló: ZIP Halo (WS2812) + ESP32 (Wemos D1 Mini)

🔌 Bekötés:

ZIP Halo LED gyűrű | ESP32 (Wemos D1 Mini)
DIN (adat) | D1 (GPIO22)
VCC (táp) | 5V (USB-ről megy)
GND | GND

🧠 Fontos: A Wemos D1 Mini ESP32-n a D1 pin = GPIO22, tehát ezt kell megadnod a kódban!

## ⚠️ Tippek ESP32-hez

Printed using ChatGPT to PDF, (https://pdfcrowd.com/chatgpt-to-pdf/?ref=chatgpt) powered by PDFCrowd HTML to PDF API. (https://pdfcrowd.com/api/html-to-pdf-api/?ref=chatgpt) | 5/8

### 1. Jelszint kompatibilitás:

ESP32 3.3V-on dolgozik, a WS2812 5V-os jelet szeret — de sok esetben 3.3V is elég.
Ha nem működik stabilan, használhatsz jelszintillesztőt (pl. 74AHCT125 vagy tranzisztor).

### 2. LED tápellátás:

Ha sok LED világít egyszerre, ne az ESP32 USB-portján keresztül tápláld őket → használj külső 5V tápot.

### 3. Zajvédelem:

Tegyél a tápra egy 1000 µF kondenzátort.
Tegyél a DIN vonalba egy 330 Ohm-os ellenállást.

## ✅ Arduino kód ESP32-re (D1 = GPIO22)

cpp

#include <Adafruit_NeoPixel.h>

#define LED_PIN | 22 | // D1 = GPIO22

#define LED_COUNT 24 | // ZIP Halo LED-ek száma

Adafruit_NeoPixel strip(LED_COUNT, LED_PIN, NEO_GRB + NEO_KHZ800);

void setup() {
strip.begin();
strip.show(); // LED-ek kikapcsolása
}

void loop() {
for(int i = 0; i < LED_COUNT; i++) { strip.setPixelColor(i, strip.Color(0, 255, 0)); // zöld strip.show();
delay(100);
strip.setPixelColor(i, 0);
}
}

## 🧪 Ha nem működik:

Próbáld meg másik GPIO-t is, pl. GPIO4 vagy GPIO5 (D2 vagy D3).
Ellenőrizd, hogy a ZIP Halo első LED-jének DIN lábára csatlakoztál-e.
Ellenőrizd, hogy a táp valóban 5V, és van-e elég áram (pl. USB-ről nem mindig elég, ha sok LED világít).

Szükség esetén:

Rajzolok neked bekötési ábrát.
Átnézem a kódot vagy a fotót a bekötésedről.

Szólj, hogyan segíthetek tovább!

Printed using ChatGPT to PDF, (https://pdfcrowd.com/chatgpt-to-pdf/?ref=chatgpt) powered by PDFCrowd HTML to PDF API. (https://pdfcrowd.com/api/html-to-pdf-api/?ref=chatgpt) | 6/8

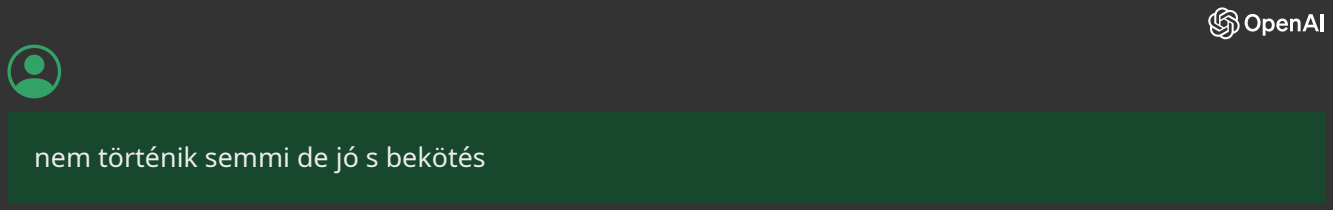
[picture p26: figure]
nem történik semmi de jó s bekötés

Oké, ha jó a bekötés, de nem történik semmi, akkor haladjunk lépésenként a hibakereséssel. A ZIP Halo LED-ek WS2812-esek, tehát működniük kell az ESP32-vel — valami apróság lehet a gond. Nézzük meg pontról pontra:

## ✅ 1. Ellenőrzés: GPIO szám és kód

ESP32-n a D1 láb = GPIO22.
Ez szerepeljen a kódban:

cpp

#define LED_PIN 22

❗️Ha véletlenül `#define LED_PIN D1` van, az nem fog működni ESP32-n!

## ✅ 2. Kód újratesztelése – minimál példa

Próbáljuk ki ezt az egyszerű villogtató kódot egyetlen LED-re:

cpp

#include <Adafruit_NeoPixel.h>

#define LED_PIN | 22 | // GPIO22 = D1

#define LED_COUNT 24 | // ZIP Halo összes LED-je

Adafruit_NeoPixel strip(LED_COUNT, LED_PIN, NEO_GRB + NEO_KHZ800);

void setup() {
strip.begin();
strip.show(); // Kikapcsolja az összes LED-et
delay(500);
}

void loop() {
strip.fill(strip.Color(255, 0, 0)); // Minden LED piros strip.show();
delay(1000);

strip.clear(); // Kikapcsolja az összes LED-et strip.show();
delay(1000);
}

## ✅ 3. Tápellátás ellenőrzése

A ZIP Halo LED-eknek stabil 5V kell. Az ESP32 USB portja nem mindig ad elég áramot.
Egy LED kb. 60 mA-t vesz fel teljes fényerőn.
Printed using ChatGPT to PDF, (https://pdfcrowd.com/chatgpt-to-pdf/?ref=chatgpt) powered by PDFCrowd HTML to PDF API. (https://pdfcrowd.com/api/html-to-pdf-api/?ref=chatgpt) | 7/8

### 24 LED → akár 1.5 A is lehet!

Ha van külső 5V tápegységed (pl. 5V 2A), használd azt.

Fontos: Közös GND kell az ESP32 és a külső tápegység között!

## ✅ 4. Ellenállás + kondenzátor

Ezek nem kötelezőek, de ajánlottak a stabil működéshez:

330Ω ellenállás az adatvezetékre (ESP32 → DIN). 1000 µF kondenzátor a ZIP Halo VCC és GND közé.

## ✅ 5. Könyvtár

Győződj meg róla, hogy az Adafruit NeoPixel könyvtár van telepítve az Arduino IDE-ben.

## ✅ 6. Alternatíva: próbálj ki másik GPIO-t

Előfordulhat, hogy GPIO22 nem működik jól WS2812-höz (ritka, de előfordul).
Próbáld meg pl. GPIO5-öt (Wemos D1 Mini-n a D3 láb):

cpp

#define LED_PIN 5

És kösd át a DIN vezetéket D3-ra.

## ✅ 7. ZIP Halo működik egyáltalán?

Ha van micro:bit-ed, próbáld ki azzal is, hogy meggyőződj róla, a LED gyűrű tényleg működik.

## Ha ezek után sem megy:

👉 Küldj egy fotót a bekötésedről (ZIP Halo + Wemos), és:

Megmondom, látok-e bekötési hibát
Végigmegyek veled a debug lépéseken

Szívesen segítek!

Printed using ChatGPT to PDF, (https://pdfcrowd.com/chatgpt-to-pdf/?ref=chatgpt) powered by PDFCrowd HTML to PDF API. (https://pdfcrowd.com/api/html-to-pdf-api/?ref=chatgpt) | 8/8

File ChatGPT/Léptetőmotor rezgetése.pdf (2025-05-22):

# Léptetőmotor rezgetése

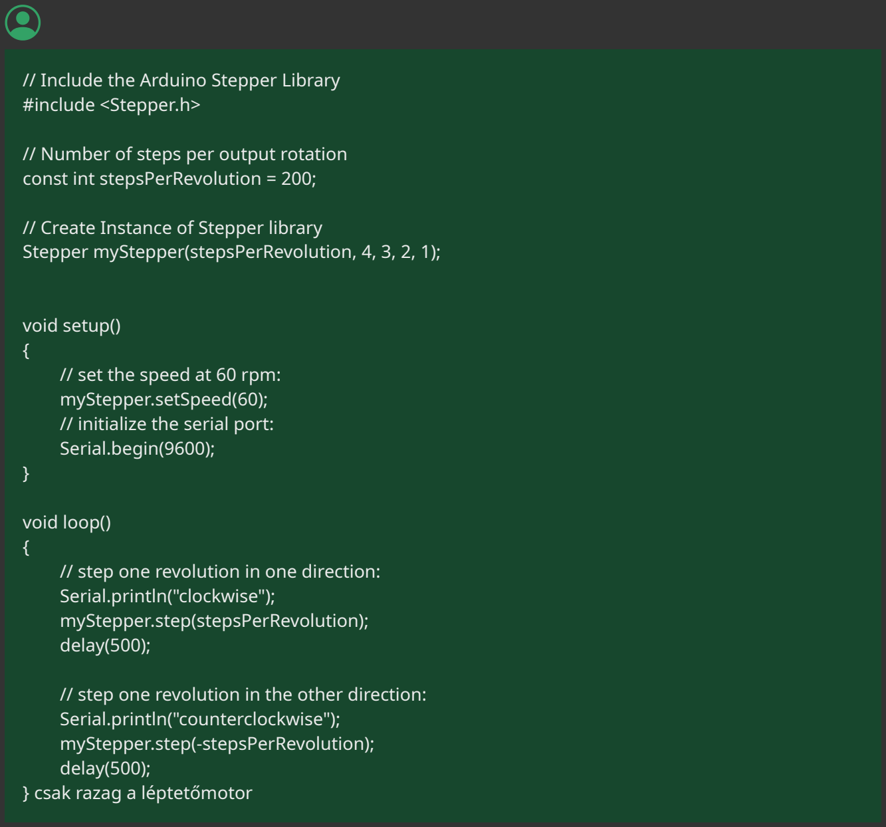
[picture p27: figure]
// Include the Arduino Stepper Library #include <Stepper.h>; // Number of steps per output rotation const int stepsPerRevolution = 200;; // Create Instance of Stepper library; void setup() {; // set the speed at 60 rpm: myStepper.setSpeed(60); // initialize the serial port: Serial.begin(9600);; void loop() {; Serial.println("clockwise"); myStepper.step(stepsPerRevolution); delay(500);; Serial.println("counterclockwise"); myStepper.step(-stepsPerRevolution); delay(500); } csak razag a léptetőmotor

Stepper myStepper(stepsPerRevolution, 4, 3, 2, 1);

// step one revolution in one direction:

// step one revolution in the other direction:

A léptetőmotorod jelenlegi programja egy teljes fordulatot tesz előre és vissza, de ha csak „rázzuk” a léptetőmotort (azaz apró mozgásokkal, előre-hátra lépegetéssel vibrációs hatást akarunk elérni), akkor néhány kisebb lépés szükséges oda-vissza, nem pedig egy teljes kör.
Itt egy módosított példa arra, hogy a léptetőmotor „rezegjen” (pl. kis lépéseket tegyen gyors egymásutánban, irányváltásokkal):

cpp

#include <Stepper.h>

const int stepsPerRevolution = 200;

Stepper myStepper(stepsPerRevolution, 4, 3, 2, 1);

void setup() {
Printed using ChatGPT to PDF, (https://pdfcrowd.com/chatgpt-to-pdf/?ref=chatgpt) powered by PDFCrowd HTML to PDF API. (https://pdfcrowd.com/api/html-to-pdf-api/?ref=chatgpt) | 1/12

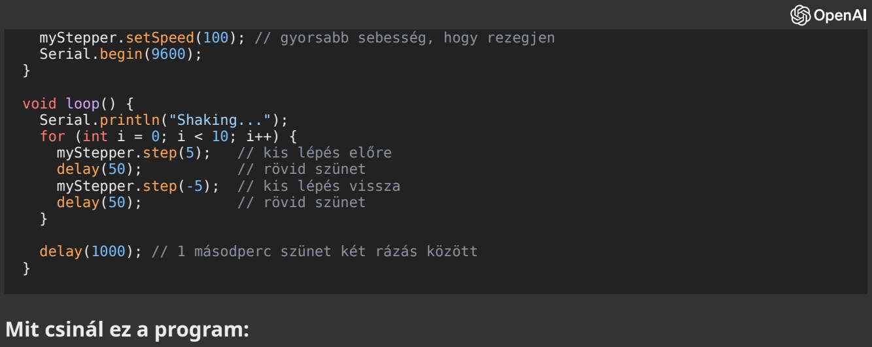
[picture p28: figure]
Serial.begin(9600);; void loop() { Serial.println("Shaking..."); for (int i = 0; i < 10; i++) {; myStepper.step(5);; // kis lépés előre; delay(50);; // rövid szünet; myStepper.step(-5); // kis lépés vissza; Mit csinál ez a program:

myStepper.setSpeed(100); // gyorsabb sebesség, hogy rezegjen

delay(1000); // 1 másodperc szünet két rázás között

A motor 5 lépést megy előre, majd 5 lépést vissza, 10-szer egymás után.
Így rezgő mozgás jön létre, mintha „ráznád” a motort.
A sebesség (100 RPM) és a lépések száma (5) finomítható, hogy erősebb vagy lágyabb legyen a hatás.

Ha más típusú mozgást szeretnél (például növekvő amplitúdójú rezgést vagy véletlenszerű irányváltást),

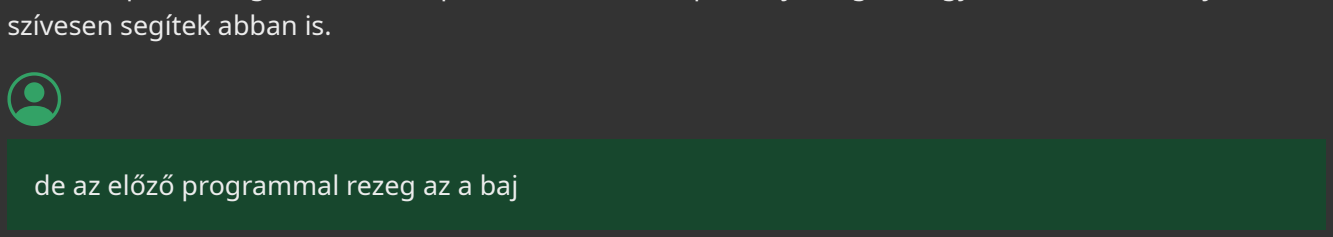
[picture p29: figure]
szívesen segítek abban is.; de az előző programmal rezeg az a baj

Köszi a pontosítást! Ha a korábbi programoddal a motor csak „rezeg” (tehát nem forog rendesen, pedig kellene), akkor néhány dolog lehet a probléma oka. Itt van egy lépésenkénti hibakeresési útmutató:

🔌 1. Helytelen bekötés / vezetékek sorrendje

A `Stepper` könyvtárban megadott lábak sorrendje nagyon fontos:

cpp

Stepper myStepper(stepsPerRevolution, 4, 3, 2, 1);

Ez azt jelenti, hogy az IN1, IN2, IN3, IN4 lábak sorrendben az Arduino 4, 3, 2, 1 lábaira vannak kötve. Ha nem ebben a sorrendben kötötted be a motor vezérlőmodulját, akkor csak „rezegni” fog, mert nem kapja a megfelelő sorrendű impulzusokat.
🛠 Ellenőrizd, hogy a motorvezérlő (pl. ULN2003 vagy hasonló) bemenetei pontosan ebben a sorrendben csatlakoznak.

⚙️ 2. Túl alacsony tápfeszültség / gyenge táp

A léptetőmotor gyakran külső tápellátást igényel (pl. 5V vagy 12V-os adapter), mert az Arduino önmagában nem képes elég áramot adni.
Printed using ChatGPT to PDF, (https://pdfcrowd.com/chatgpt-to-pdf/?ref=chatgpt) powered by PDFCrowd HTML to PDF API. (https://pdfcrowd.com/api/html-to-pdf-api/?ref=chatgpt) | 2/12

Ha csak USB-ről megy a motor, nem lesz elég erős, csak rezegni fog vagy ki se mozdul.
🛠 Próbáld külső tápról (pl. 12V adapter) hajtani, és ellenőrizd, hogy a GND közös az Arduino és a motorvezérlő között.

⚡ 3. Sebesség túl alacsony vagy túl magas

A `.setSpeed(60);` beállítás megfelelő lehet, de:

Ha túl alacsony (pl. 5 RPM alatt), a motor nehezen indul.
Ha túl magas (pl. 200+ RPM), a motor nem bírja követni a lépéseket → szintén rezgés.

🛠 Próbáld módosítani az RPM értéket, pl.:

cpp

myStepper.setSpeed(100);

🔄 4. Lépések száma nem megfelelő

Ha a motorod nem 200 lépéses (pl. 28BYJ-48 esetén ez 4096 lépés egy teljes körhöz), akkor ez is okozhat furcsa viselkedést.
🛠 Próbáld megnézni a motor pontos típusát, és ennek megfelelően állítsd be:

cpp

const int stepsPerRevolution = 4096; // ha pl. 28BYJ-48

✅ Összefoglalva:

A „csak rezeg” probléma valószínű oka(i):

1. Hibás vezeték sorrend (lábak rosszul bekötve).
2. Kevés tápellátás – külső tápegység kell.
3. Túl alacsony vagy túl magas sebesség.
4. Rossz `stepsPerRevolution` érték.

Ha küldesz egy fotót a bekötésről vagy megírod a motor típusát (pl. 28BYJ-48 vagy NEMA 17), még

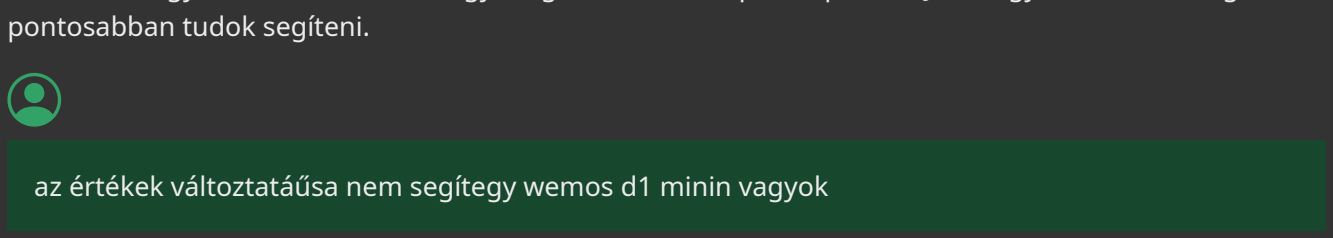
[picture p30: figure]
pontosabban tudok segíteni.

az értékek változtatáűsa nem segítegy wemos d1 minin vagyok

Köszi a visszajelzést, és az, hogy Wemos D1 Mini-t használsz, nagyon fontos információ! Ez magában hordozza a legvalószínűbb okát annak, hogy a léptetőmotorod csak „rezeg” és nem forog:

Printed using ChatGPT to PDF, (https://pdfcrowd.com/chatgpt-to-pdf/?ref=chatgpt) powered by PDFCrowd HTML to PDF API. (https://pdfcrowd.com/api/html-to-pdf-api/?ref=chatgpt) | 3/12

## ⚠️ A probléma: A `Stepper` könyvtár nem működik jól ESP8266-tal (Wemos D1 Mini)

A `Stepper.h` könyvtár az ATmega328-alapú Arduinókra lett optimalizálva (pl. UNO, Nano), és nem kompatibilis jól az ESP8266 (Wemos D1 Mini) architektúrájával. Ezért jön elő a jelenség, hogy a motor csak rezeg vagy furcsán viselkedik.

## ✅ Megoldás: Használj másik könyvtárat, amely működik ESP8266-on is

A javasolt megoldás egy kompatibilis motorvezérlő könyvtár használata, pl.:
🔧 AccelStepper könyvtár

Az `AccelStepper` könyvtár ESP8266-kompatibilis és sokkal megbízhatóbb: Példa kód Wemos D1 Mini-hez:

cpp

#include <AccelStepper.h>

// Define pins for motor driver IN1-IN4 #define IN1 D1
#define IN2 D2

#define IN3 D3

#define IN4 D4

// Create stepper motor object (4 wire mode)
AccelStepper stepper(AccelStepper::FULL4WIRE, IN1, IN3, IN2, IN4);

void setup() {
stepper.setMaxSpeed(1000); | // beállított maximális sebesség
stepper.setSpeed(200); | // aktuális mozgási sebesség
}

void loop() {
stepper.runSpeed(); // folyamatos mozgás
}

Ez a kód folyamatos forgást indít el a motoron, és biztosan működik Wemos D1 Mini-vel.

## 🛠 Fontos bekötési megjegyzés:

D1 = GPIO5
D2 = GPIO4
D3 = GPIO0
D4 = GPIO2

Győződj meg róla, hogy a vezérlőmodul (pl. ULN2003) IN1–IN4 bemenetei ehhez passzolnak.

Printed using ChatGPT to PDF, (https://pdfcrowd.com/chatgpt-to-pdf/?ref=chatgpt) powered by PDFCrowd HTML to PDF API. (https://pdfcrowd.com/api/html-to-pdf-api/?ref=chatgpt) | 4/12

## 📦 Telepítés:

Menj az Arduino IDE-ben a Könyvtárkezelőbe, és:

Keress rá: `AccelStepper`
Telepítsd a megfelelő könyvtárat

Ha szeretnéd, küldhetek egy komplett példát rázáshoz vagy pontos forgatáshoz. Csak írd meg, milyen típusú motorod van (pl. 28BYJ-48?), és hogyan kötötted be.

Köszi az infót! Ha a motor forog, de gyenge a nyomaték, az azt jelenti, hogy működik az alapvezérlés, de valami miatt nem tud elég erőt kifejteni. Ez nem szoftveres, hanem inkább elektromos vagy mechanikai probléma.
Nézzük végig a lehetséges okokat és megoldásokat:

## 🔋 1. Nem megfelelő vagy gyenge tápellátás

A Wemos D1 Mini önmagában nem tud elég áramot adni egy léptetőmotor meghajtásához. Ha a motorod csak az USB-ről kap áramot, akkor szinte biztos, hogy ez a fő probléma.
✅ Megoldás:

Adj külső tápot a motorvezérlőnek (pl. 5V vagy 12V adapter). Csatlakoztasd a motorvezérlő tápbemenetére (pl. ULN2003: VCC/GND). A GND legyen közös az Arduino és a motorvezérlő között!

👉 Pl. ha ULN2003 modult használsz:

VCC: külső 5V (nem Wemos 5V láb!)
GND: közös a Wemos és a táp
IN1–IN4: D1–D4, vagy más GPIO

## ⚙️ 2. Nem megfelelő stepper sebesség / gyorsítás

Ha túl gyorsan próbálod indítani a motort, az nem tudja követni a jeleket, és „elgyengül” → nyomatékvesztés.
✅ Megoldás:

Lassabban indítsd el (pl. `setSpeed(100)` helyett `setSpeed(50)`).

Printed using ChatGPT to PDF, (https://pdfcrowd.com/chatgpt-to-pdf/?ref=chatgpt) powered by PDFCrowd HTML to PDF API. (https://pdfcrowd.com/api/html-to-pdf-api/?ref=chatgpt) | 5/12

Használj gyorsulásvezérlést `AccelStepper`-rel:

cpp

stepper.setAcceleration(200); stepper.setMaxSpeed(300);
stepper.setSpeed(100);

Ez megakadályozza, hogy a motor „megszökjön” induláskor.

## 🧠 3. Nem megfelelő lépésmód

Ha 28BYJ-48 vagy hasonló motorod van, akkor lehet féllépés (half-step) módban megy, ami gyengébb nyomatékot ad.
✅ Megoldás:

Próbáld `AccelStepper::FULL4WIRE` vagy `AccelStepper::HALF4WIRE` módokkal,
és nézd meg, melyik ad jobb nyomatékot.

## 🔩 4. Mechanikai ellenállás / túl nagy terhelés

Ha valamit mozgat a motor (pl. egy tengelyt, kart, fogaskereket), és az túl nehéz vagy szorul, akkor úgy tűnhet, hogy a motor gyenge.
✅ Megoldás:

Próbáld motor terhelés nélkül.
Ha így erősebb, akkor mechanikán kell lazítani vagy áttételt alkalmazni.

## 🎯 Összefoglalva:

Probléma | Megoldás
Motor forog, de gyenge | Külső táp 5–12V
Túl gyors indulás | Lassabb sebesség, gyorsulásvezérlés
Féllépéses mód | Próbáld FULL4WIRE móddal
Terhelés túl nagy | Teszteld üresjáratban

Ha küldesz egy fényképet a bekötésedről vagy leírod pontosan, mit vezérel a motor (fogaskerék, szíj,

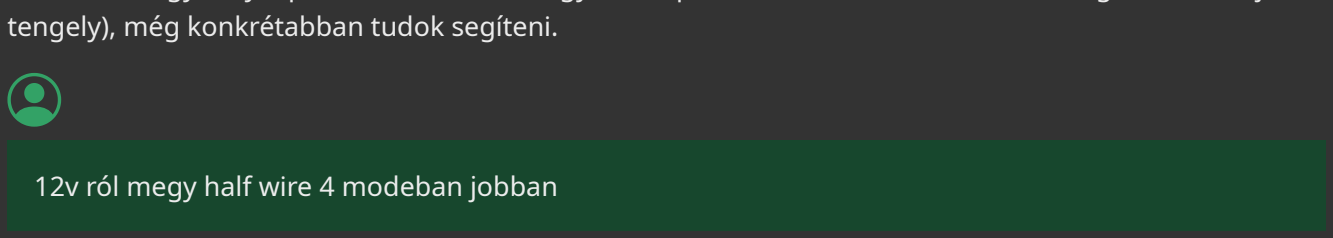
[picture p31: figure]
tengely), még konkrétabban tudok segíteni.; 12v ról megy half wire 4 modeban jobban

Printed using ChatGPT to PDF, (https://pdfcrowd.com/chatgpt-to-pdf/?ref=chatgpt) powered by PDFCrowd HTML to PDF API. (https://pdfcrowd.com/api/html-to-pdf-api/?ref=chatgpt) | 6/12

Nagyon jó hír, hogy már 12V-ról megy, és hogy HALF4WIRE módban jobban működik – ezek alapján a motorod valószínűleg egy 28BYJ-48, vagy legalábbis valami unipoláris, belső áttételes léptetőmotor. 🧠 Amit most tudunk:

Motor működik, forog.
12V táp használata segített – ez megfelelő áramerősséget ad.
HALF4WIRE módban erősebb, azaz jól megy féllépés módban, ez finomabb, de gyengébb működés, viszont néha mechanikusan hatékonyabb, mert simábban indul.

## ✅ Tippek a nyomaték további növeléséhez

### 1. Használj FULL4WIRE módot próbára

Ez általában nagyobb nyomatékot ad, cserébe kevésbé sima a mozgás.

cpp

AccelStepper stepper(AccelStepper::FULL4WIRE, IN1, IN3, IN2, IN4);

Nézd meg, így is elég simán indul-e. Ha igen, maradj FULL4WIRE módban a nyomaték miatt.

### 2. Gyorsulásvezérlés beállítása

Ez megakadályozza, hogy a motor lemaradjon induláskor, és így több erőt tud kifejteni:

cpp

stepper.setMaxSpeed(400);
stepper.setAcceleration(200);

### 3. Áttétel vagy mechanikai segítség

Ha nagy terhet kell mozgatnia, akkor gondolkozz egy fogaskerekes áttételben vagy csigahajtásban.
A 28BYJ-48 már belső áttételes, de ha más motorod van, ezt lehet külsőleg pótolni.

### 4. Áramkorlát ellenőrzése (ha van driver pl. A4988)

Ha nem ULN2003-at használsz, hanem pl. A4988, DRV8825 stb., akkor a potméterrel állítható az áramerősség.
Több áram = több nyomaték, de vigyázat, ne melegedjen túl.

## Példa: erős és biztonságos forgatás

Printed using ChatGPT to PDF, (https://pdfcrowd.com/chatgpt-to-pdf/?ref=chatgpt) powered by PDFCrowd HTML to PDF API. (https://pdfcrowd.com/api/html-to-pdf-api/?ref=chatgpt) | 7/12

cpp; #include <AccelStepper.h>; #define IN1 D1 #define IN2 D2 #define IN3 D3 #define IN4 D4; void setup() {; void loop() {

AccelStepper stepper(AccelStepper::FULL4WIRE, IN1, IN3, IN2, IN4);

stepper.setMaxSpeed(400); | // max sebesség
stepper.setAcceleration(200); // gyorsulás
stepper.setSpeed(200); | // aktuális sebesség

stepper.runSpeed(); // folyamatos forgás

Ha szeretnél vezérelhető mozgást (pl. menjen 180 fokot és álljon meg), abban is tudok segíteni – csak szólj.
Illetve ha a motor típusa mégis más, mint a 28BYJ-48, vagy gyanús valami, küldj képet, és megnézzük

pontosabban.; egy nema17 nek mennyi a nyomatéka?

A NEMA 17 nem egy konkrét motor, hanem egy méretosztály (43.2 × 43.2 mm-es négyzetes homlokfelület). Ezért a nyomaték típustól és gyártótól függően nagyon eltérő lehet.

## 📏 Általános NEMA 17 nyomatékértékek:

Típus | Tápfeszültség | Áram | Tartónyomaték (Holding torque)
Gyenge típus | 12V, 1A | ~0.3 Nm (30 N·cm)
Átlagos | 12–24V, 1.5–2A | ~0.4–0.5 Nm (40–50 N·cm)
Erősebb NEMA 17 | 24V, 2A+ | akár 0.6–0.8 Nm (60–80 N·cm)

## 🧠 Fontos tudni:

A tartónyomaték (holding torque) azt jelzi, mekkora erővel tud a motor ellenállni a mozgásnak áram alatt, de álló helyzetben.
Forgó nyomaték (running torque) kisebb lehet, főleg magas fordulaton.
Az áram és a feszültség növelésével nő a nyomaték – ehhez stepper driver kell (pl. A4988, TMC2208, DRV8825).
Általában a 24V tápellátás hatékonyabb, mint a 12V – főleg magasabb fordulatszám mellett.
Printed using ChatGPT to PDF, (https://pdfcrowd.com/chatgpt-to-pdf/?ref=chatgpt) powered by PDFCrowd HTML to PDF API. (https://pdfcrowd.com/api/html-to-pdf-api/?ref=chatgpt) | 8/12

## 🎯 Példa konkrét típusra:

Egy gyakori típus:

Model: 17HS4401
Tartónyomaték: 0.40 Nm (40 N·cm) Áram: 1.7 A
Lépésszög: 1.8°
Táp: 12–24V

## ️ Vezérléshez ajánlott:

Driver: A4988, DRV8825, TMC2209
Táp: 24V/2A (optimális)
Hűtés: szükséges, ha nagy áramon használod

Ha megírod, hogy milyen típusú NEMA 17-ed van (felirat a motoron), akkor pontosabb adatot tudok adni. Vagy küldhetsz képet a címkéről.

Linking .pio\build\d1_mini\firmware.elf c:/users/bence/.platformio/packages/toolchain-xtensa/bin/../lib/gcc/xtensa-lx106-elf/10.3.0/../../../../xtensa-lx106-elf/bin/ld.exe: .pio\build\d1_mini\src\main.cpp.o:(.text.setup+0xc):
undefined reference to `_ZN12AccelStepper11setMaxSpeedEf'
`c:/users/bence/.platformio/packages/toolchain-xtensa/bin/../lib/gcc/xtensa-lx106-elf/10.3.0/../../../../xtensa-lx106-elf/bin/ld.exe: .pio\build\d1_mini\src\main.cpp.o:(.text.setup+0x10):
undefined reference to `_ZN12AccelStepper8setSpeedEf'
`c:/users/bence/.platformio/packages/toolchain-xtensa/bin/../lib/gcc/xtensa-lx106-elf/10.3.0/../../../../xtensa-lx106-elf/bin/ld.exe: .pio\build\d1_mini\src\main.cpp.o: in
function `setup':
`main.cpp:(.text.setup+0x23): undefined reference to `_ZN12AccelStepper11setMaxSpeedEf' `c:/users/bence/.platformio/packages/toolchain-xtensa/bin/../lib/gcc/xtensa-lx106-elf/10.3.0/../../../../xtensa-lx106-elf/bin/ld.exe: .pio\build\d1_mini\src\main.cpp.o:(.text.loop+0x0):
undefined reference to `_ZN12AccelStepper8runSpeedEv'
`c:/users/bence/.platformio/packages/toolchain-xtensa/bin/../lib/gcc/xtensa-lx106-elf/10.3.0/../../../../xtensa-lx106-elf/bin/ld.exe: .pio\build\d1_mini\src\main.cpp.o: (.text.startup._GLOBAL__sub_I_stepper+0x0): undefined reference to `_ZN12AccelStepperC1Ehhhhhb' `c:/users/bence/.platformio/packages/toolchain-xtensa/bin/../lib/gcc/xtensa-lx106-elf/10.3.0/../../../../xtensa-lx106-elf/bin/ld.exe: .pio\build\d1_mini\src\main.cpp.o: in
function `_GLOBAL__sub_I_stepper':
`main.cpp:(.text.startup._GLOBAL__sub_I_stepper+0x1a): undefined reference to

`_ZN12AccelStepperC1Ehhhhhb'
`collect2.exe: error: ld returned 1 exit status
*** [.pio\build\d1_mini\firmware.elf] Error 1 ======================================================================= [FAILED]
Printed using ChatGPT to PDF, (https://pdfcrowd.com/chatgpt-to-pdf/?ref=chatgpt) powered by PDFCrowd HTML to PDF API. (https://pdfcrowd.com/api/html-to-pdf-api/?ref=chatgpt) | 9/12

Took 5.38 seconds =======================================================================; with exit code: 1.

* The terminal process "C:\Users\Bence\.platformio\penv\Scripts\platformio.exe 'run'" terminated

* Terminal will be reused by tasks, press any key to close it.

Ez a hibaüzenet azt jelenti, hogy a `AccelStepper` könyvtár nincs megfelelően beépítve a projektedbe, így a linker nem találja a könyvtár függvényeit.

## 💥 Hibák magyarázata:

`undefined reference to 'AccelStepper::setMaxSpeed'` stb. → ezek mind azt jelzik, hogy a
függvénydefiníciók hiányoznak → azaz nincs belinkelve a könyvtár forrása.

## ✅ Megoldás lépésről lépésre PlatformIO-ban

1. 📦 Győződj meg arról, hogy a `AccelStepper` könyvtár telepítve van

Menj a `platformio.ini` fájlodhoz, és adj hozzá egy sort a `lib_deps` alá:

ini

[env:d1_mini]
platform = espressif8266
board = d1_mini
framework = arduino
lib_deps =
mike-matera/AccelStepper@^1.61

Vagy ha a `lib_deps` már létezik:

ini

lib_deps =
mike-matera/AccelStepper

Alternatív megoldásként a könyvtár telepítése terminálból:

bash

pio lib install "mike-matera/AccelStepper"

2. 🧹 Tisztítsd le a buildet és építsd újra

A PlatformIO-ban futtasd:

Printed using ChatGPT to PDF, (https://pdfcrowd.com/chatgpt-to-pdf/?ref=chatgpt) powered by PDFCrowd HTML to PDF API. (https://pdfcrowd.com/api/html-to-pdf-api/?ref=chatgpt) | 10/12

bash; pio run --target clean pio run

3. 📁 Győződj meg arról, hogy a forráskódodban helyesen van include-olva:

cpp

#include <AccelStepper.h>

## 🔁 Ellenőrzés után próbáld újrafordítani

Ha minden rendben van, a `undefined reference` hibák megszűnnek, és a firmware szépen lefordul.

Ha még mindig hibát kapsz, írd be ide a `platformio.ini` fájlod teljes tartalmát és a `main.cpp` elejét,

hogy ellenőrizni tudjam pontosan.; a ./ include ben van

Köszi, hogy írtad: ha a `AccelStepper.h` a saját `./include` mappádban van, akkor PlatformIO nem tudja automatikusan belinkelni a hozzá tartozó `.cpp` fájlt, kivéve ha azt is odatetted és helyesen konfiguráltad.
A `header` (`.h`) fájl önmagában nem elég – a linkerhiba azért van, mert a hozzá tartozó forrás (`.cpp`) nincs beépítve.

## ✅ Megoldási lehetőségek

🔧 1. Helyes módszer: Használd a PlatformIO könyvtárkezelőt (`lib_deps`)

Ez a legmegbízhatóbb módszer:

`platformio.ini`:

ini

[env:d1_mini]
platform = espressif8266
board = d1_mini
framework = arduino
lib_deps =
mike-matera/AccelStepper

Ez letölti a teljes könyvtárat, `.cpp`-estül, és automatikusan beépíti. Ez a javasolt módszer.

Printed using ChatGPT to PDF, (https://pdfcrowd.com/chatgpt-to-pdf/?ref=chatgpt) powered by PDFCrowd HTML to PDF API. (https://pdfcrowd.com/api/html-to-pdf-api/?ref=chatgpt) | 11/12

️ 2. Ha ragaszkodsz a saját `./include` könyvtárhoz:

A `AccelStepper.cpp` fájlt is tedd be a `src/` könyvtárba, vagy Külön hozz létre egy saját könyvtárat a `lib/` mappában:

Fájlstruktúra például:

markdown

lib/
└── AccelStepper/
├── AccelStepper.h
└── AccelStepper.cpp

PlatformIO automatikusan felismeri a `lib/AccelStepper/`-t mint könyvtárat.

A `include/` mappa PlatformIO-ban csak fejlécekre (header files) való, nem fordul le benne
`.cpp`.

## 📌 Összefoglalás:

Módszer | Előny | Hátrány
`lib_deps` a `platformio.ini`-ben | Automatikus, működik | Internet kell
`lib/AccelStepper/` saját könyvtárként | Offline működik, testreszabható | Neked kell karbantartani
`include/` használata | Nem működik `.cpp` nélkül | Nem javasolt forrásokhoz

Írd meg, melyik megoldás szimpatikus, és segítek beállítani. Ha szeretnéd, küldheted a mappa/fájlszerkezetet, és ránézek!

Printed using ChatGPT to PDF, (https://pdfcrowd.com/chatgpt-to-pdf/?ref=chatgpt) powered by PDFCrowd HTML to PDF API. (https://pdfcrowd.com/api/html-to-pdf-api/?ref=chatgpt) | 12/12

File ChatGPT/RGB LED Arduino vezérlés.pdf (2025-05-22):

# RGB LED Arduino vezérlés

Rgb ledet arduino uno val hogy tudok vezérelni

Egy RGB LED vezérlése Arduino Uno-val viszonylag egyszerű, csak néhány alkatrészre és pár sornyi kódra van szükség. Az alábbiakban bemutatom az alapokat:

### 1. Szükséges eszközök:

### 1 db RGB LED (közös katód vagy közös anód) 3 db 220Ω ellenállás

Breadboard és jumper kábelek
Arduino Uno

### 2. Bekötés (közös katód esetén):

Tegyük fel, hogy közös katódú RGB LED-ed van (azaz a közös lábat GND-re kell kötni):

LED lábak:
Hosszú láb (közös katód): GND
R (piros): 220Ω ellenálláson keresztül → D9 G (zöld): 220Ω ellenálláson keresztül → D10 B (kék): 220Ω ellenálláson keresztül → D11

### 3. Arduino kód (PWM vezérlés):

cpp

int redPin = 9;
int greenPin = 10;
int bluePin = 11;

void setup() {
pinMode(redPin, OUTPUT);
pinMode(greenPin, OUTPUT); pinMode(bluePin, OUTPUT);
}

void loop() {
setColor(255, 0, 0); // piros delay(1000);
setColor(0, 255, 0); // zöld delay(1000);
setColor(0, 0, 255); // kék delay(1000);
setColor(255, 255, 0); // sárga
delay(1000);
Printed using ChatGPT to PDF, (https://pdfcrowd.com/chatgpt-to-pdf/?ref=chatgpt) powered by PDFCrowd HTML to PDF API. (https://pdfcrowd.com/api/html-to-pdf-api/?ref=chatgpt) | 1/2

setColor(255, 255, 255); // fehér delay(1000);; analogWrite(redPin, red); analogWrite(greenPin, green); analogWrite(bluePin, blue);

void setColor(int red, int green, int blue) {

### 4. Megjegyzés közös anódú LED esetén:

Ha a LED közös anódú, akkor a közös lábat 5V-ra kell kötni, és az `analogWrite()` értékeket invertálni kell:
pl. `analogWrite(redPin, 255 - red);`

Ha szeretnél dinamikus színeffekteket (pl. színátmenetet, villogást stb.), szívesen segítek azok kódjában

A pwm pin az hány fokozatot tud kiadni?

Az Arduino Uno PWM (Pulse Width Modulation) jele 8 bites felbontású, vagyis:
PWM fokozatok száma: 2⁸ = 256
Ez azt jelenti, hogy a `analogWrite(pin, value)` függvényen keresztül megadható érték:

0 (0% kitöltési tényező, azaz állandóan kikapcsolva)
255 (100% kitöltési tényező, azaz állandóan bekapcsolva)

Tehát összesen 256 különböző szint között tudsz választani, ez elég finom szabályozást tesz lehetővé például egy LED fényerejénél.

Ha ennél finomabb vezérlést szeretnél (pl. zene vagy világítási hangulat alapján), vannak mikrokontrollerek 10 vagy 12 bites PWM-mel is, illetve lehetőség van digitális-analóg átalakító (DAC) használatára is.

Printed using ChatGPT to PDF, (https://pdfcrowd.com/chatgpt-to-pdf/?ref=chatgpt) powered by PDFCrowd HTML to PDF API. (https://pdfcrowd.com/api/html-to-pdf-api/?ref=chatgpt) | 2/2

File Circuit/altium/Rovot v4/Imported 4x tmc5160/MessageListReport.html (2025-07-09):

Altium customize

# Message List

Date: | | 2025. 06. 19.
Time: | | 17:03:21
Elapsed Time: | | 00:00:00

Class | Document | Source | Message | Time | Date | No.
[Error] | CM5IO.SchDoc | Compiler | Missing child-sheet in CM5_GPIO.SchDoc in Symbol CM5_GPIO ( Ethernet, GPIO, SDCARD) at 5100mil,28700mil. | 17:01:42 | 2025. 06. 19. | 1
[Error] | CM5IO.SchDoc | Compiler | Missing child-sheet in CM5_HighSpeed.SchDoc in Symbol CM5_HighSpeed at 5100mil,31750mil. | 17:01:42 | 2025. 06. 19. | 2
[Error] | CM5IO.SchDoc | Compiler | Missing child-sheet in INA226.SchDoc in Symbol INA226 at 12100mil,26200mil. | 17:01:42 | 2025. 06. 19. | 3
[Error] | CM5IO.SchDoc | Compiler | Missing child-sheet in PCIe-M2.SchDoc in Symbol PCIe-M2 at 8450mil,31750mil. | 17:01:42 | 2025. 06. 19. | 4
[Error] | CM5IO.SchDoc | Compiler | Missing child-sheet in PSUs.SchDoc in Symbol PSUs at 9300mil,28700mil. | 17:01:42 | 2025. 06. 19. | 5
[Error] | CM5IO.SchDoc | Compiler | Missing child-sheet in USB2-HUB.SchDoc in Symbol USB2-HUB at 1500mil,23150mil. | 17:01:42 | 2025. 06. 19. | 6
[Error] | CM5IO.SchDoc | Compiler | Missing child-sheet in YD-ESP32-S3.SchDoc in Symbol YD-ESP32-S3 at 4500mil,23100mil. | 17:01:42 | 2025. 06. 19. | 7
[Error] | charge-manager.SchDoc | Compiler | Multiple top level documents: charge-manager.SchDoc has been used | 17:01:42 | 2025. 06. 19. | 8
[Warning] | CM5IO.SchDoc | Compiler | Off grid H1 at 900mil,26575mil | 17:01:42 | 2025. 06. 19. | 9
[Warning] | CM5IO.SchDoc | Compiler | Off grid H2 at 900mil,26375mil | 17:01:42 | 2025. 06. 19. | 10
[Warning] | CM5IO.SchDoc | Compiler | Off grid H3 at 900mil,26175mil | 17:01:42 | 2025. 06. 19. | 11
[Warning] | CM5IO.SchDoc | Compiler | Off grid H4 at 900mil,25975mil | 17:01:42 | 2025. 06. 19. | 12
[Warning] | CM5IO.SchDoc | Compiler | Off grid H5 at 1725mil,26575mil | 17:01:42 | 2025. 06. 19. | 13
[Warning] | CM5IO.SchDoc | Compiler | Off grid H6 at 1725mil,26375mil | 17:01:42 | 2025. 06. 19. | 14
[Warning] | CM5IO.SchDoc | Compiler | Off grid H7 at 1725mil,26175mil | 17:01:42 | 2025. 06. 19. | 15
[Warning] | CM5IO.SchDoc | Compiler | Off grid H8 at 1725mil,25975mil | 17:01:42 | 2025. 06. 19. | 16
[Warning] | CM5IO.SchDoc | Compiler | Off grid Net Label +3.3v at 4725mil,30100mil | 17:01:42 | 2025. 06. 19. | 17
[Warning] | CM5IO.SchDoc | Compiler | Off grid Net Label +5v at 4725mil,30250mil | 17:01:42 | 2025. 06. 19. | 18
[Warning] | CM5IO.SchDoc | Compiler | Unconnected line (3700mil,22600mil) To (4500mil,22600mil) | 17:01:42 | 2025. 06. 19. | 19
[Warning] | CM5IO.SchDoc | Compiler | Unconnected line (3700mil,22700mil) To (4500mil,22700mil) | 17:01:42 | 2025. 06. 19. | 20
[Warning] | CM5IO.SchDoc | Compiler | Unconnected line (3700mil,22850mil) To (4500mil,22850mil) | 17:01:42 | 2025. 06. 19. | 21
[Warning] | CM5IO.SchDoc | Compiler | Unconnected line (3700mil,22950mil) To (4500mil,22950mil) | 17:01:42 | 2025. 06. 19. | 22
[Warning] | CM5IO.SchDoc | Compiler | Unconnected line (5300mil,28700mil) To (5300mil,29300mil) | 17:01:42 | 2025. 06. 19. | 23
[Warning] | CM5IO.SchDoc | Compiler | Unconnected line (5450mil,28700mil) To (5450mil,29300mil) | 17:01:42 | 2025. 06. 19. | 24
[Warning] | CM5IO.SchDoc | Compiler | Unconnected line (5750mil,28700mil) To (5750mil,29300mil) | 17:01:42 | 2025. 06. 19. | 25
[Warning] | CM5IO.SchDoc | Compiler | Unconnected line (5900mil,28700mil) To (5900mil,29300mil) | 17:01:42 | 2025. 06. 19. | 26
[Warning] | CM5IO.SchDoc | Compiler | Unconnected line (6200mil,28700mil) To (6200mil,29300mil) | 17:01:42 | 2025. 06. 19. | 27
[Warning] | CM5IO.SchDoc | Compiler | Unconnected line (6400mil,28700mil) To (6400mil,29300mil) | 17:01:42 | 2025. 06. 19. | 28
[Warning] | CM5IO.SchDoc | Compiler | Unconnected line (6700mil,28700mil) To (6700mil,29300mil) | 17:01:42 | 2025. 06. 19. | 29
[Warning] | CM5IO.SchDoc | Compiler | Unconnected line (7100mil,28700mil) To (7100mil,29300mil) | 17:01:42 | 2025. 06. 19. | 30
[Warning] | CM5IO.SchDoc | Compiler | Unconnected line (7350mil,30100mil) To (8450mil,30100mil) | 17:01:42 | 2025. 06. 19. | 31
[Warning] | CM5IO.SchDoc | Compiler | Unconnected line (7350mil,30250mil) To (8450mil,30250mil) | 17:01:42 | 2025. 06. 19. | 32
[Warning] | CM5IO.SchDoc | Compiler | Unconnected line (7350mil,30400mil) To (8450mil,30400mil) | 17:01:42 | 2025. 06. 19. | 33
[Warning] | CM5IO.SchDoc | Compiler | Unconnected line (7350mil,30550mil) To (8450mil,30550mil) | 17:01:42 | 2025. 06. 19. | 34
[Warning] | CM5IO.SchDoc | Compiler | Unconnected line (7350mil,30750mil) To (8450mil,30750mil) | 17:01:42 | 2025. 06. 19. | 35
[Warning] | CM5IO.SchDoc | Compiler | Unconnected line (7350mil,30850mil) To (8450mil,30850mil) | 17:01:42 | 2025. 06. 19. | 36
[Warning] | CM5IO.SchDoc | Compiler | Unconnected line (7350mil,31000mil) To (8450mil,31000mil) | 17:01:42 | 2025. 06. 19. | 37
[Warning] | CM5IO.SchDoc | Compiler | Unconnected line (7350mil,31100mil) To (8450mil,31100mil) | 17:01:42 | 2025. 06. 19. | 38
[Warning] | CM5IO.SchDoc | Compiler | Unconnected line (7350mil,31300mil) To (8450mil,31300mil) | 17:01:42 | 2025. 06. 19. | 39
[Warning] | CM5IO.SchDoc | Compiler | Unconnected line (7350mil,31400mil) To (8450mil,31400mil) | 17:01:42 | 2025. 06. 19. | 40
[Warning] | charge-manager.SchDoc | Compiler | Unconnected Port POWER-OUT at 4450mil,5200mil | 17:01:42 | 2025. 06. 19. | 41
[Warning] | charge-manager.SchDoc | Compiler | Unconnected Port usb-c_cc1 at 3000mil,4450mil | 17:01:42 | 2025. 06. 19. | 42
[Warning] | charge-manager.SchDoc | Compiler | Unconnected Port usb-c_cc at 3000mil,4650mil | 17:01:42 | 2025. 06. 19. | 43
[Warning] | charge-manager.SchDoc | Compiler | Unconnected Port usb-c_vbus at 2850mil,5300mil | 17:01:42 | 2025. 06. 19. | 44
Cross Reference | 4x tmc5160.PrjPcb | Automatic Cross References | Cross References are incomplete due to lack of sheet number(s) | 17:01:42 | 2025. 06. 19. | 45

Back to top

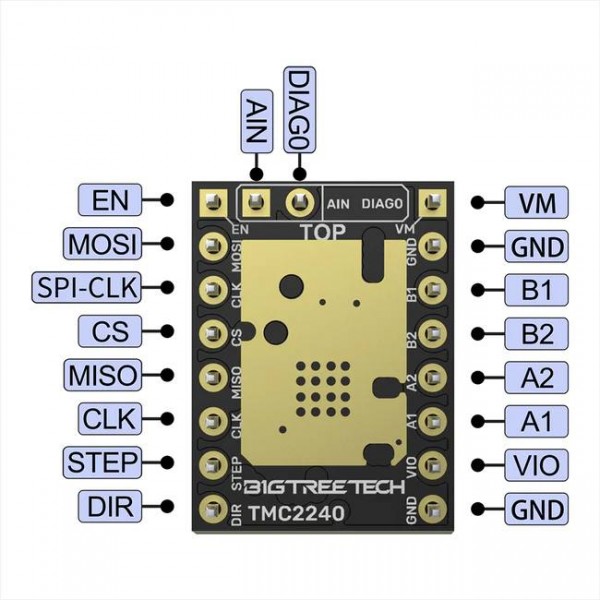
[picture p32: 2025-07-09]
Datasheets/tmc2240_pinout.jpg

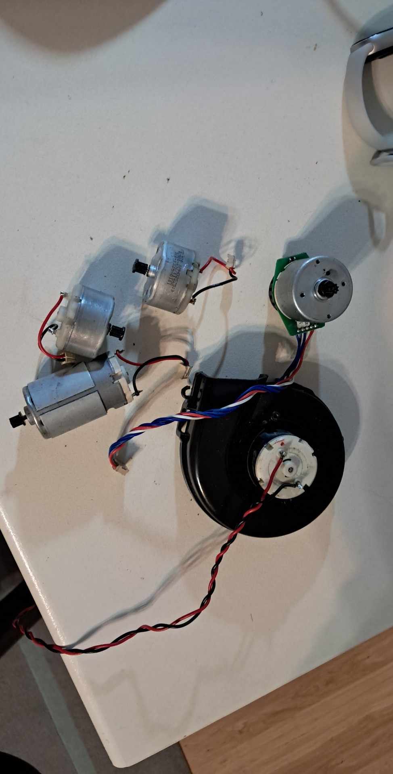
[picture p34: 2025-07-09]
media/basic/494826427_1249387796701021_5553236919915959918_n.jpg

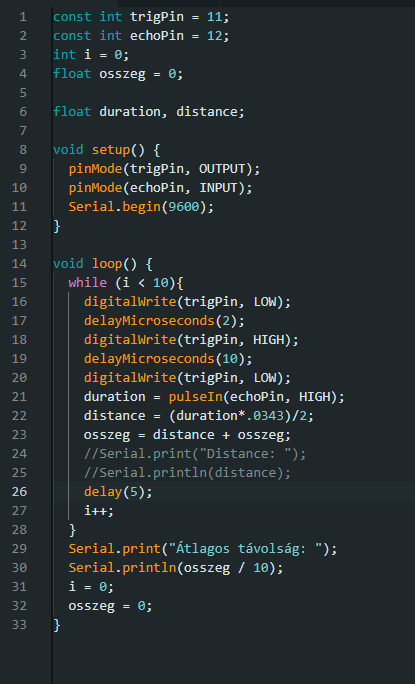
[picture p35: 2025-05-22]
media/basic/491217968_1586724459382511_125483047907498779_n.png

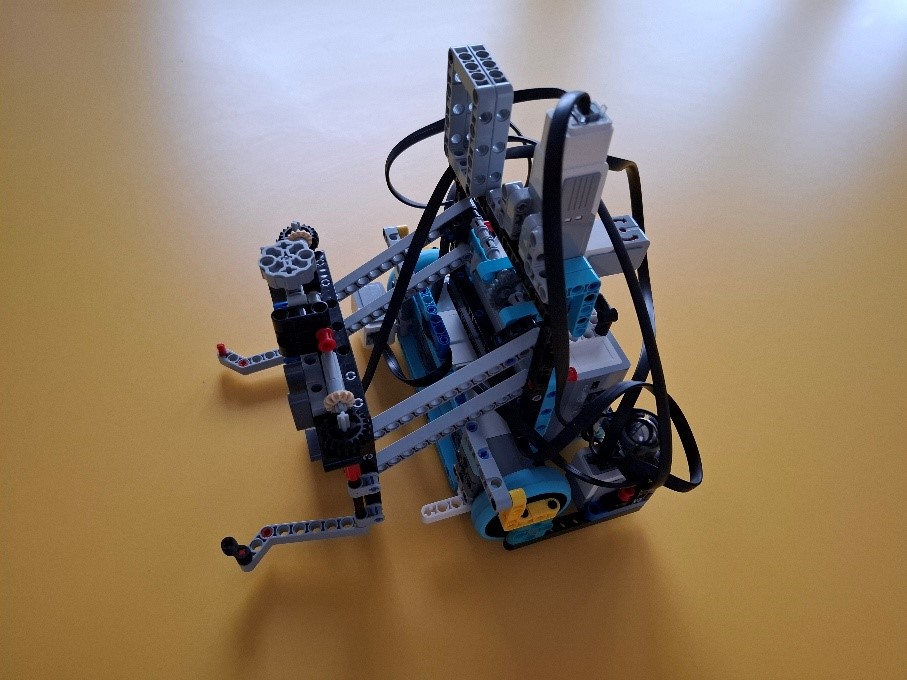
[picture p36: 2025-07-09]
media/lego robot/robot.jpg

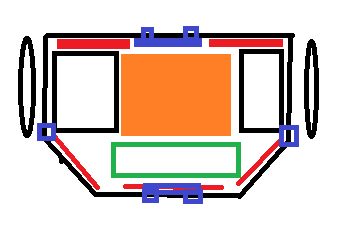
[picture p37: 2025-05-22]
Robot 3d/basic/0.1.png

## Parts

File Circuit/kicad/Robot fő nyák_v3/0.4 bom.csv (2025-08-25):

Id | Designator | Footprint | Quantity | Designation | Supplier and ref
1 | TP13,TP12,TP5,TP16,TP6 | TestPoint_Pad_D2.0mm | 5 | TestPoint
2 | D15,D36,D28,D8,D23,D10,D37,D26,D7,D32,D11,D43,D18,D39,D17,D27,D42,D9,D35,D21,D29,D14,D33,D30,D41,D38,D40,D34,D13,D19,D24,D25,D22,D12,D31,D20 | D_1206_3216Metric | 36 | LED
3 | C114,C74,C115,C76,C63,C149,C147,C151,C61,C150,C158,C56,C59,C40,C148,C152,C57,C38,C51,C45,C156,C157,C48,C62,C159 | C_0805_2012Metric | 25 | 4,7uf
4 | R57,R92,R86,R93,R87 | R_0805_2012Metric | 5 | 330
5 | R88,R90,R95,R163,R85,R84,R91,R174,R94,R89,R14 | R_0805_2012Metric | 11 | 10k
6 | C43,C153,C41,C154,C46,C64,C44,C144,C66,C145 | C_0805_2012Metric | 10 | 100n
7 | R56,R60,R66 | R_0805_2012Metric | 3 | 33k
8 | CT5 | CP_EIA-3528-21_Kemet-B | 1 | 10uf
9 | SERVO2,SERVO4,SERVO1,SERVO3 | JST_PH_B3B-PH-K_1x03_P2.00mm_Vertical | 4 | Conn_01x03_Socket
10 | M6,M7,M5,M4 | JST_PH_B6B-PH-K_1x06_P2.00mm_Vertical | 4 | Stepper_Motor_unipolar_6pin
11 | R34,R39,R42,R43,R45,R48,R37,R47,R38,R44,R35,R36,R40,R46,R33,R41 | R_1206_3216Metric | 16 | 0.025Ω
12 | R82,R81,R80,R67,R77,R68,R79,R78,R76 | R_0805_2012Metric | 9 | R_LED
13 | C37,C34,C141,C31,C25,C33,C26,C101,C29,C35,C36,C32,C23,C28,C24,C22,C30,C27,C100 | C_0805_2012Metric | 19 | 1uf
14 | R165,R173 | R_0805_2012Metric | 2 | 34,8k
15 | J14 | Amphenol_F32Q-1A7x1-11060_1x60-1MP_P0.5mm_Horizontal | 1 | Conn_01x60_MountingPin
16 | DC6,DC5,DC4,DC1,DC2,DC3 | JST_PH_B2B-PH-K_1x02_P2.00mm_Vertical | 6 | Conn_01x02_Socket
17 | U49,U50,U51,U48 | TMC2209 | 4 | TMC2240_SILENTSTEPSTICK
18 | C52,C70,C50 | C_0805_2012Metric | 3 | 1.2nF
19 | U26,U16,U25,U20,U27,U23,U19,U22,U24,U28,U18,U17,U30,U15,U29,U21 | VSSOP-10_3x3mm_P0.5mm | 16 | INA226
20 | R160,R175 | R_0805_2012Metric | 2 | 154k
21 | U40,U35,U44,U42,U43,U41 | SOT-23-6 | 6 | AP22815AWU
22 | R53 | R_0805_2012Metric | 1 | 100
23 | U67 | TSSOP-28_4.4x9.7mm_P0.65mm | 1 | PCA9685PW
24 | U33,U34,U31 | SOIC-8-1EP_3.9x4.9mm_P1.27mm_EP2.95x4.9mm_Mask2.71x3.4mm_ThermalVias | 3 | AP64501SP-13
25 | R61,R51,R49 | R_0805_2012Metric | 3 | 10R
26 | L1,L6,L7,L3,L4 | L_KOHERelec_MDA7030 | 5 | HCM0703-3R3-R
27 | J31,J32 | JST_PH_B2B-PH-K_1x02_P2.00mm_Vertical | 2 | Conn_01x02_Pin
28 | R161,R178 | R_0805_2012Metric | 2 | 36k
29 | J1 | AMASS_XT60-M_1x02_P7.20mm_Vertical | 1 | XT60-M
30 | R62,R58,R64 | R_0805_2012Metric | 3 | 100R
31 | R52,R63,R54 | R_0805_2012Metric | 3 | 12K 1%
32 | R177,R162 | R_0805_2012Metric | 2 | 510k
33 | C96,C97,C98,C99 | CP_Elec_8x10 | 4 | 470uf
34 | R59 | R_0805_2012Metric | 1 | 210k
35 | R171,R172,R169,R166,R170 | R_0805_2012Metric | 5 | 47k
36 | C55,C47,C53,C49,C72,C68 | C_0805_2012Metric | 6 | 68pf
37 | R50 | R_0805_2012Metric | 1 | 1k
38 | C146,C155 | C_0805_2012Metric | 2 | 330pf
39 | R164,R176 | R_0805_2012Metric | 2 | 2,2k
40 | Q1 | SOT-23 | 1 | bss138
41 | DSW1 | SW_DIP_SPSTx08_Slide_Copal_CHS-08A_W5.08mm_P1.27mm_JPin | 1 | SW_DIP_x08
42 | R55 | R_0805_2012Metric | 1 | 105k
43 | U52 | SSOP-24_5.3x8.2mm_P0.65mm | 1 | TB6612FNG
44 | J25 | JST_PH_B3B-PH-K_1x03_P2.00mm_Vertical | 1 | Conn_01x03_Pin
45 | J26 | PinHeader_2x03_P2.54mm_Vertical | 1 | Conn_02x03_Counter_Clockwise
46 | R65 | R_0805_2012Metric | 1 | 178k
47 | U53 | SSOP-28_3.9x9.9mm_P0.635mm | 1 | MCP23S17_SO
48 | J16 | PinSocket_1x12_P2.54mm_Vertical | 1 | Conn_01x12
49 | U39,U36 | SOP65P640X120-29N | 2 | LTC3119EFE_PBF

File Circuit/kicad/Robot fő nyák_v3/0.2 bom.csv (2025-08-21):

Reference | Value | Datasheet | Footprint | Qty | DNP | # | Field4 | Field5 | Field6 | Field7 | Field8 | Part Description | Description | Check_prices | MANUFACTURER | MAXIMUM_PACKAGE_HEIGHT | MF | MP | PARTREV | Package | Description_1 | Price | SNAPEDA_PN | STANDARD | Sim.Device | Sim.Pins | Sim.Type | SnapEDA_Link | Url | Availability
BT1 | Battery_Cell | https://www.keyelco.com/userAssets/file/M65p9.pdf | Connector_JST:JST_PH_B2B-PH-K_1x02_P2.00mm_Vertical | 1 |  | 1 | Digikey | 36-3034-ND | 3034 | Keystone |  | Battery Retainer Coin, 20.0mm 1 Cell SMD (SMT) Tab
C1,C3,C4 | 10u | https://search.murata.co.jp/Ceramy/image/img/A01X/G101/ENG/GRM21BR71A106KA73-01.pdf | Capacitor_Tantalum_SMD:CP_EIA-3528-21_Kemet-B | 3 |  | 2 | Digikey | 490-14381-1-ND | GRM21BR71A106KA73L | Murata | 111893011 | 10uF 10% 10V Ceramic Capacitor X7R 0805 (2012 Metric)
C2 | 100uF | ~ | Capacitor_Tantalum_SMD:CP_EIA-7343-31_Kemet-D | 1 |  | 3 | Mouser | 667-EEF-CX0J101R |  | Panasonic |  | Capacitor, SP-Cap, 100u, 6.3V, 15mR ESR
C5,C6,C7,C11 | 100n | https://search.murata.co.jp/Ceramy/image/img/A01X/G101/ENG/GRM155R71C104KA88-01.pdf | Capacitor_SMD:C_0805_2012Metric | 4 |  | 4 | Farnell | 2611911 | RM EMK105 B7104KV-F | TAIYO YUDEN EUROPE GMBH | 110091611 | 0.1uF 10% 16V Ceramic Capacitor X7R 0402 (1005 Metric)
C8,C9,C10,C17,C18,C19,C20,C21,C22,C23,C24,C25,C26,C27,C28,C29,C30,C31,C32,C33,C34,C35,C36,C37,C80,C81,C82,C83,C85,C86,C87,C88,C89,C90,C91,C92,C93,C94,C95,C100,C101,C103,C104,C105,C106,C107,C110,C111,C116,C117,C118,C119,C121,C124,C125,C127,C128,C134,C135,C136,C138,C141 | 1uf | ~ | Capacitor_SMD:C_0805_2012Metric | 62 |  | 5 |  |  |  |  |  |  | Unpolarized capacitor
C12,C14 | 22pf | ~ | Capacitor_SMD:C_0805_2012Metric | 2 |  | 6 | Digikey | 490-17672-1-ND | GJM1555C1H270JB01D | Murata | UCAP00738 | 27pF 5% 50V Ceramic Capacitor C0G, NP0 0402 (1005 Metric) | Unpolarized capacitor
C13,C42,C79,C84 | 100nf | ~ | Capacitor_SMD:C_0805_2012Metric | 4 |  | 7 |  |  |  |  |  |  | Unpolarized capacitor
C15 | 10u | ~ | Capacitor_Tantalum_SMD:CP_EIA-3528-21_Kemet-B | 1 |  | 8 | Digikey | 490-14381-1-ND | GRM21BR71A106KA73L | Murata | 111893011 | 10uF 10% 10V Ceramic Capacitor X7R 0805 (2012 Metric) | Unpolarized capacitor
C16 | 470uF | ~ | Capacitor_SMD:CP_Elec_8x10 | 1 |  | 9 | Mouser | 667-EEF-CX0J101R |  |  |  | Capacitor, SP-Cap, 100u, 6.3V, 15mR ESR
C38,C40,C56,C57,C59,C61,C62,C63,C74,C76,C114,C115,C147,C148,C149,C150,C151,C152,C156,C157,C158,C159 | 4,7uf | ~ | Capacitor_SMD:C_0805_2012Metric | 22 |  | 10 |  |  |  |  |  |  | Unpolarized capacitor
C39,C47,C49,C68 | 68pf | ~ | Capacitor_SMD:C_0805_2012Metric | 4 |  | 11 |  |  |  |  |  |  | Unpolarized capacitor
C41,C43,C44,C46,C64,C66,C144,C145,C153,C154 | 100n | ~ | Capacitor_SMD:C_0805_2012Metric | 10 |  | 12 | Farnell | 2611911 | RM EMK105 B7104KV-F | TAIYO YUDEN EUROPE GMBH | 110091611 | 0.1uF 10% 16V Ceramic Capacitor X7R 0402 (1005 Metric) | Unpolarized capacitor
C50,C52,C70 | 1.2nF | ~ | Capacitor_SMD:C_0805_2012Metric | 3 |  | 13 | Digikey | 490-16429-1-ND | GCM155R71H122KA37D | Murata |  | 1200pF 10% 10V Ceramic Capacitor X5R 0402 (1005 Metric) | Unpolarized capacitor
C53,C55,C72 | 68pf | ~ | Capacitor_SMD:C_0805_2012Metric | 3 |  | 14 | Digikey | 490-17672-2-ND | GJM1555C1H270JB01D | Murata |  | 27pF 5% 50V Ceramic Capacitor C0G, NP0 0402 (1005 Metric) | Unpolarized capacitor
C78 | 100uf | ~ | Capacitor_Tantalum_SMD:CP_EIA-7343-31_Kemet-D | 1 |  | 15 |  |  |  |  |  |  | Unpolarized capacitor
C96,C97,C98,C99,C102,C139,C140,C142,C143 | 470uf | ~ | Capacitor_SMD:CP_Elec_8x10 | 9 |  | 16 |  |  |  |  |  |  | Polarized capacitor
C108,C109 | 0.1uF |  | Capacitor_SMD:C_0805_2012Metric | 2 |  | 17
C112,C113 | 22pF |  | Capacitor_SMD:C_0805_2012Metric | 2 |  | 18
C120,C122 | 22pf | ~ | Capacitor_SMD:C_0805_2012Metric | 2 |  | 19 |  |  |  |  |  |  | Unpolarized capacitor
C123,C126,C137 | 0.022-μF | ~ | Capacitor_SMD:C_0805_2012Metric | 3 |  | 20 |  |  |  |  |  |  | Unpolarized capacitor
C129,C130 | 100uf | ~ | Capacitor_Tantalum_SMD:CP_EIA-7343-31_Kemet-D | 2 |  | 21 |  |  |  |  |  |  | Polarized capacitor
C131 | 10uf | ~ | Capacitor_Tantalum_SMD:CP_EIA-3528-21_Kemet-B | 1 |  | 22 |  |  |  |  |  |  | Polarized capacitor
C132,C133 | 1uf | ~ | Capacitor_SMD:C_0805_2012Metric | 2 |  | 23 |  |  |  |  |  |  | Polarized capacitor
C146,C155 | 350pf | ~ | Capacitor_SMD:C_0805_2012Metric | 2 |  | 24 | Digikey | 490-17672-2-ND | GJM1555C1H270JB01D | Murata |  | 27pF 5% 50V Ceramic Capacitor C0G, NP0 0402 (1005 Metric) | Unpolarized capacitor
CT1,CT2,CT3 | 100uf | ~ | Capacitor_Tantalum_SMD:CP_EIA-7343-31_Kemet-D | 3 |  | 25 |  |  |  |  |  |  | Polarized capacitor, small symbol
CT4,CT5,CT6,CT7,CT8,CT9 | 10uf | ~ | Capacitor_Tantalum_SMD:CP_EIA-3528-21_Kemet-B | 6 |  | 26 |  |  |  |  |  |  | Polarized capacitor, small symbol
D1,D3 | LED Green | http://optoelectronics.liteon.com/upload/download/DS22-2000-226/LTST-S270KGKT.pdf | Diode_SMD:D_1206_3216Metric | 2 |  | 27 | Digikey | LTST-S270KGKT | SML-A12M8TT86N | Rohm | 650263301 | Green 572nm LED Indication - Discrete 2.2V 2-SMD, No Lead
D2 | LED Red | http://optoelectronics.liteon.com/upload/download/DS22-2000-210/LTST-S270KRKT.pdf | Diode_SMD:D_1206_3216Metric | 1 |  | 28 | Digikey | LTST-S270KRKT | SML-A12U8TT86Q | Rohm | 650295101 | Red 620nm LED Indication - Discrete 2.2V 2-SMD, No Lead
D4,D5,D6,D8,D9,D10,D11 | LED | ~ | Diode_SMD:D_1206_3216Metric | 7 |  | 29 |  |  |  |  |  |  | Light emitting diode
D7,D12,D13,D14,D15,D16 | LED | ~ | Diode_SMD:D_1206_3216Metric | 6 |  | 30 |  |  |  |  |  |  | Light emitting diode |  |  |  |  |  |  |  |  |  |  |  |  | 1=K 2=A
DC1,DC2,DC3,DC4,DC5,DC6 | Conn_01x02_Socket | ~ | Connector_JST:JST_PH_B2B-PH-K_1x02_P2.00mm_Vertical | 6 |  | 31 |  |  |  |  |  |  | Generic connector, single row, 01x02, script generated
DSI1,DSI2 | Conn_01x22_Female | https://www.hirose.com/product/document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 | CM5IO:Hirose_FH12-22S-0.5SH_1x22-1MP_P0.50mm_Horizontal | 2 |  | 32 | Mouser | 798-FH12-22S-0.5SH55 | FH12-22S-0.5SH55 | Hirose |  | 22 Position FFC, FPC Connector Contacts, Bottom 0.020" (0.50mm) Surface Mount, Right Angle
DSW1,DSW2 | SW_DIP_x08 | ~ | Button_Switch_SMD:SW_DIP_SPSTx08_Slide_Copal_CHS-08A_W5.08mm_P1.27mm_JPin | 2 |  | 33 |  |  |  |  |  |  | 8x DIP Switch, Single Pole Single Throw (SPST) switch, small symbol
ESP1 | ESP32-S3-WROOM-2 | https://www.espressif.com/sites/default/files/documentation/esp32-s3-wroom-2_datasheet_en.pdf | RF_Module:ESP32-S3-WROOM-2 | 1 |  | 34 |  |  |  |  |  |  | RF Module, 2.4 GHz, Wi-Fi, Bluetooth, BLE, ESP32--S3R8V
GPIO1 | THD-20-R | https://www.toby.co.uk/uploads/publications/1673.pdf | Connector_PinHeader_2.54mm:PinHeader_2x20_P2.54mm_Vertical | 1 |  | 35 | Toby | THD-20-R | THD-20-R | Toby | UCON00511 | PinHeader_2x20_P2.54mm_Vertical
HS1,HS2 | Heatsink | ~ | TestPoint:TestPoint_Pad_1.0x1.0mm | 2 |  | 36 |  |  |  |  |  |  | Heatsink
I2C_0x70_1,I2C_0x70_2,I2C_0x70_3,I2C_0x70_4,I2C_0x70_5,I2C_0x70_6,I2C_0x70_7,I2C_0x70_8 | Conn_01x04_Pin | ~ | Connector_JST:JST_PH_B4B-PH-K_1x04_P2.00mm_Vertical | 8 |  | 37 |  |  |  |  |  |  | Generic connector, single row, 01x04, script generated
I2C_0x71_1,I2C_0x71_2,I2C_0x71_3,I2C_0x71_4,I2C_0x71_5,I2C_0x71_7,I2C_0x71_8 | Conn_01x04_Pin | ~ | Connector_JST:JST_PH_B4B-PH-K_1x04_P2.00mm_Vertical | 7 |  | 38 |  |  |  |  |  |  | Generic connector, single row, 01x04, script generated
I2C_1,I2C_2 | Conn_01x04_Pin | ~ | Connector_JST:JST_PH_B4B-PH-K_1x04_P2.00mm_Vertical | 2 |  | 39 |  |  |  |  |  |  | Generic connector, single row, 01x04, script generated
J2 | USB3_A | ~ | CM5IO:MTCONN_UBAF30-D2011 | 1 |  | 40 |  | UBAF30-D2011 | UBAF30-D2011 | Mtconn |  | Dual USB 3 connector
J3,J4 | 690-019-298-412 | https://www.tme.eu/Document/f15dffbcfad8545e17826f72d36911c8/206A-SEAN-R03.pdf | CM5IO:EDAC 690-019-298-412 | 2 |  | 41 | Farnell | 2614936 | 690-019-298-412 | EDAC | UCON00802 | HDMI Connector, Right Angle, 19 Contacts, Receptacle, Surface Mount, Surface Mount Right Angle
J5 | MagJack-A70-112-331N126 | https://p.globalsources.com/IMAGES/PDT/SPEC/690/K1160305690.pdf | CM5IO:TRJG0926HENL | 1 |  | 42 |  | TRJG0926HENL | TRJG0926HENL | Trxcon | UCON00900 | Gigabit Ethernet Magjack
J6 | Bus_M.2_Socket_M |  | CM5IO:M.2 M Key socket | 1 |  | 43 |  | MTSSD03-67MSW337 | MTSSD03-67MSW337 | MTCONN |  | M.2 M Key connector | M.2 Socket 3 Mechanical Key M
J7 | 690-008-221-904 | Conn USB Type A RCP 4/4 POS Solder RA Thru-Hole 8 Terminal 2 Port Tray | CM5IO:MOLEX_USB_67298-4090 | 1 |  | 44 | Farnell | 2751688 | None | Molex | None | USB-A (USB TYPE-A), Stacked Receptacle Connector 8 Position Through Hole, Right Angle
J8,J9,J10 | USB_C_Receptacle_USB2.0_16P | https://www.usb.org/sites/default/files/documents/usb_type-c.zip | Connector_USB:USB_C_Receptacle_Palconn_UTC16-G | 3 |  | 45 |  |  |  |  |  |  | USB 2.0-only 16P Type-C Receptacle connector
J11,J13 | THD-02-R | https://www.toby.co.uk/uploads/publications/1673.pdf | Connector_PinHeader_2.54mm:PinHeader_2x02_P2.54mm_Vertical | 2 |  | 46 | Toby | THD-02-R | 151-604-425-761 | EDAC | UCON00791 | PinHeader_2x02_P2.54mm_Vertical
J12 | Conn_01x04_Socket | ~ | Connector_JST:JST_PH_B4B-PH-K_1x04_P2.00mm_Vertical | 1 |  | 47 |  |  |  |  |  |  | Generic connector, single row, 01x04, script generated
J14,J15 | Conn_01x60_MountingPin | ~ | Connector_FFC-FPC:Amphenol_F32Q-1A7x1-11060_1x60-1MP_P0.5mm_Horizontal | 2 |  | 48 |  |  |  |  |  |  | "Generic connectable mounting pin connector, single row, 01x60, script generated"
J16 | Conn_01x12 | ~ | Connector_PinSocket_2.54mm:PinSocket_1x12_P2.54mm_Vertical | 1 |  | 49 |  |  |  |  |  |  | Generic connector, single row, 01x12, script generated (kicad-library-utils/schlib/autogen/connector/)
J17,J18,J21,J22,J23,J24 | Conn_01x02_Pin | ~ | Connector_PinHeader_2.54mm:PinHeader_2x01_P2.54mm_Vertical | 6 |  | 50 |  |  |  |  |  |  | Generic connector, single row, 01x02, script generated
J19,J20,J28 | Conn_01x08_Pin | ~ | Connector_PinHeader_2.54mm:PinHeader_1x08_P2.54mm_Vertical | 3 |  | 51 |  |  |  |  |  |  | Generic connector, single row, 01x08, script generated
J25,J29 | Conn_01x03_Pin | ~ | Connector_JST:JST_PH_B3B-PH-K_1x03_P2.00mm_Vertical | 2 |  | 52 |  |  |  |  |  |  | Generic connector, single row, 01x03, script generated
J31,J32 | Conn_01x02_Pin | ~ | Connector_JST:JST_PH_B2B-PH-K_1x02_P2.00mm_Vertical | 2 |  | 53 |  |  |  |  |  |  | Generic connector, single row, 01x02, script generated
JI2C_0x71_6 | Conn_01x04_Pin | ~ | Connector_JST:JST_PH_B4B-PH-K_1x04_P2.00mm_Vertical | 1 |  | 54 |  |  |  |  |  |  | Generic connector, single row, 01x04, script generated
L1,L3,L4,L6,L7 | HCM0703-3R3-R | https://www.bourns.com/docs/Product-Datasheets/SRN6045TA.pdf | Inductor_SMD:L_KOHERelec_MDA7030 | 5 |  | 55 | Farnell | 2616889 | SRN6045TA-3R3Y | Bourns |  | 3.3µH Semi-Shielded Wirewound Inductor 7.8A 21mOhm Nonstandard
M1,M2 | M.2 Solder Nut |  |  | 2 |  | 56 |  |  |  |  |  | Solder nut for M.2 slot
M3 | M.2 Screw |  |  | 1 |  | 57 |  |  |  |  |  | M.2 Screw
M4,M5,M6,M7 | Stepper_Motor_unipolar_6pin | http://www.infineon.com/dgdl/Application-Note-TLE8110EE_driving_UniPolarStepperMotor_V1.1.pdf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 | Connector_JST:JST_PH_B6B-PH-K_1x06_P2.00mm_Vertical | 4 |  | 58 |  |  |  |  |  |  | 6-wire unipolar stepper motor
Module1 | ComputeModule5-CM5 |  | CM5IO:Raspberry-Pi-5-Compute-Module | 1 |  | 59 | Amphenol | 2x 10164227-1001A1RLF | 2x 10164227-1001A1RLF | Hirose |  | 100 Position Connector Receptacle, Center Strip Contacts Surface Mount Gold | RaspberryPi Compute module 5
Q2,Q3 | bc akármi | https://www.onsemi.com/pub/Collateral/BC818-D.pdf | Package_TO_SOT_SMD:SOT-23 | 2 |  | 60 |  |  |  |  |  |  | 0.8A Ic, 45V Vce, NPN Transistor, SOT-23
R1 | 15K 1% | https://fscdn.rohm.com/en/products/databook/datasheet/passive/resistor/chip_resistor/mcr-e.pdf | Resistor_SMD:R_0805_2012Metric | 1 |  | 61 | Farnell | 9239375 | MCR01MZPF1502 | Rohm | 120891581 | Resistor 15K M1005 1% 63mW
R2,R3,R4,R121,R122,R123,R124,R125,R126,R127,R128,R129,R130,R131,R132,R133,R134,R135,R136,R137,R138,R139,R140,R141,R142,R143,R144,R145,R146,R147,R148,R149,R150,R151,R152 | 2.2K 1% | https://fscdn.rohm.com/en/products/databook/datasheet/passive/resistor/chip_resistor/mcr-e.pdf | Resistor_SMD:R_0805_2012Metric | 35 |  | 62 | Farnell |  |  |  |  | Resistor 2.2K M1005 1% 63mW
R5,R6,R7 | 4.7k | ~ | Resistor_SMD:R_0805_2012Metric | 3 |  | 63 |  |  |  |  |  |  | Resistor
R8,R15 | 1k | https://fscdn.rohm.com/en/products/databook/datasheet/passive/resistor/chip_resistor/mcr-e.pdf | Resistor_SMD:R_0805_2012Metric | 2 |  | 64 | Farnell | 9239235 | RK73H1ETTP1001F | KOA EUROPE GMBH | 125049511 | Resistor 1K M1005 1% 63mW
R9 | 1k | https://fscdn.rohm.com/en/products/databook/datasheet/passive/resistor/chip_resistor/mcr-e.pdf | Resistor_SMD:R_0603_1608Metric | 1 |  | 65 | Farnell | 9239235 | RK73H1ETTP1001F | KOA EUROPE GMBH | 125049511 | Resistor 1K M1005 1% 63mW
R10,R14,R18,R72,R73,R74,R75,R84,R85,R88,R89,R90,R91,R94,R95,R101,R102,R155,R156,R157,R158,R163,R174 | 10k | ~ | Resistor_SMD:R_0805_2012Metric | 23 |  | 66 |  |  |  |  |  |  | Resistor
R11,R53 | 100 | ~ | Resistor_SMD:R_0805_2012Metric | 2 |  | 67 |  |  |  |  |  |  | Resistor
R12,R13 | 470R | https://fscdn.rohm.com/en/products/databook/datasheet/passive/resistor/chip_resistor/mcr-e.pdf | Resistor_SMD:R_0805_2012Metric | 2 |  | 68 | Farnell | 9239197 | RK73G1ETQTP4700D | KOA EUROPE GMBH | 120887981 | Resistor 470R M1005 1% 63mW
R16,R17,R27,R28 | 2.2K 1% | ~ | Resistor_SMD:R_0805_2012Metric | 4 |  | 69 | Farnell | 9239278 | RK73G1ETQTP2201D | KOA EUROPE GMBH | 120889581 | Resistor 2.2K M1005 1% 63mW | Resistor
R19,R20,R21,R25 | 36K 1% | ~ | Resistor_SMD:R_0805_2012Metric | 4 |  | 70 | Farnell | 1458788 | MCR01MZPF3602 | Rohm |  | Resistor 36K M1005 1% 63mW | Resistor
R22,R52,R54,R63 | 12K 1% | ~ | Resistor_SMD:R_0805_2012Metric | 4 |  | 71 | Farnell | 9239367 | MCR01MZPF1202 | Rohm |  | Resistor 12K M1005 1% 63mW | Resistor
R23,R24,R29,R30,R31,R32 | 5.1K 1% | ~ | Resistor_SMD:R_0805_2012Metric | 6 |  | 72 | Farnell | 9239278 | RK73G1ETQTP2201D | KOA EUROPE GMBH | 120889581 | Resistor 2.2K M1005 1% 63mW | Resistor
R26 | 15K 1% | ~ | Resistor_SMD:R_0805_2012Metric | 1 |  | 73 | Farnell | 9239375 | MCR01MZPF1502 | Rohm | 120891581 | Resistor 15K M1005 1% 63mW | Resistor
R33,R34,R35,R36,R37,R38,R39,R40,R41,R42,R43,R44,R45,R46,R47,R48 | 0.025Ω | ~ | Resistor_SMD:R_1206_3216Metric | 16 |  | 74 |  |  |  |  |  |  | Resistor |  |  |  |  |  |  |  |  |  |  |  |  |  |  |  | https://hu.farnell.com/vishay/wfma2512r0250fea/res-0r025-3w-2512-metal-plate/dp/3102734
R49,R51,R61 | 10R | ~ | Resistor_SMD:R_0805_2012Metric | 3 |  | 75 | Farnell | 9238999 | RC0402FR-0710RL | Yageo | URES00256 | Resistor 10R M1005 1% 63mW | Resistor
R50,R69,R70,R71 | 1k | ~ | Resistor_SMD:R_0805_2012Metric | 4 |  | 76 |  |  |  |  |  |  | Resistor
R55 | 105k | ~ | Resistor_SMD:R_0805_2012Metric | 1 |  | 77 | Farnell | 9239430 | RK73G1ETQTP4702D | KOA EUROPE GMBH | 120892781 | Resistor 47K M1005 1% 63mW | Resistor
R56,R60,R66 | 33k | ~ | Resistor_SMD:R_0805_2012Metric | 3 |  | 78 | Farnell | 9239375 | MCR01MZPF1502 | Rohm | 120891581 | Resistor 15K M1005 1% 63mW | Resistor
R57,R86,R87,R92,R93,R113,R114 | 330 | ~ | Resistor_SMD:R_0805_2012Metric | 7 |  | 79 |  |  |  |  |  |  | Resistor
R59 | 210k | ~ | Resistor_SMD:R_0805_2012Metric | 1 |  | 80 | Farnell | 9239430 | RK73G1ETQTP4702D | KOA EUROPE GMBH | 120892781 | Resistor 47K M1005 1% 63mW | Resistor
R65 | 178k | ~ | Resistor_SMD:R_0805_2012Metric | 1 |  | 81 | Farnell | 9239430 | RK73G1ETQTP4702D | KOA EUROPE GMBH | 120892781 | Resistor 47K M1005 1% 63mW | Resistor
R104,R105,R120 | 47k | ~ | Resistor_SMD:R_0805_2012Metric | 3 |  | 82 |  |  |  |  |  |  | Resistor
R106,R107 | 1.5-kΩ | ~ | Resistor_SMD:R_0805_2012Metric | 2 |  | 83 |  |  |  |  |  |  | Resistor
R108 | 22 | ~ | Resistor_SMD:R_0805_2012Metric | 1 |  | 84 |  |  |  |  |  |  | Resistor
R109 | 22Ω | ~ | Resistor_SMD:R_0805_2012Metric | 1 |  | 85 |  |  |  |  |  |  | Resistor
R110 | 1M | ~ | Resistor_SMD:R_0805_2012Metric | 1 |  | 86 |  |  |  |  |  |  | Resistor
R111,R112 | 16 | ~ | Resistor_SMD:R_0805_2012Metric | 2 |  | 87 |  |  |  |  |  |  | Resistor
R115,R116,R117,R118,R119 | 10K | ~ | Resistor_SMD:R_0805_2012Metric | 5 |  | 88 |  |  |  |  |  |  | Resistor
R160,R175 | 154k | ~ | Resistor_SMD:R_0805_2012Metric | 2 |  | 89 | Farnell | 9239375 | MCR01MZPF1502 | Rohm | 120891581 | Resistor 15K M1005 1% 63mW | Resistor
R161,R178 | 36k | ~ | Resistor_SMD:R_0805_2012Metric | 2 |  | 90 | Farnell | 9239375 | MCR01MZPF1502 | Rohm | 120891581 | Resistor 15K M1005 1% 63mW | Resistor
R162,R177 | 510k | ~ | Resistor_SMD:R_0805_2012Metric | 2 |  | 91 | Farnell | 9239375 | MCR01MZPF1502 | Rohm | 120891581 | Resistor 15K M1005 1% 63mW | Resistor
R164,R176 | 2,2k | ~ | Resistor_SMD:R_0805_2012Metric | 2 |  | 92 |  |  |  |  |  |  | Resistor
R165,R173 | 34,8k | ~ | Resistor_SMD:R_0805_2012Metric | 2 |  | 93 |  |  |  |  |  |  | Resistor
R166,R169,R170,R171,R172 | 47k | ~ | Resistor_SMD:R_0805_2012Metric | 5 |  | 94 | Farnell | 9239375 | MCR01MZPF1502 | Rohm | 120891581 | Resistor 15K M1005 1% 63mW | Resistor
SERVO1,SERVO2,SERVO3,SERVO4 | Conn_01x03_Socket | ~ | Connector_JST:JST_PH_B3B-PH-K_1x03_P2.00mm_Vertical | 4 |  | 95 |  |  |  |  |  |  | Generic connector, single row, 01x03, script generated
SPEAKER1 | Conn_01x02_Pin | ~ | Connector_JST:JST_PH_B2B-PH-K_1x02_P2.00mm_Vertical | 1 |  | 96 |  |  |  |  |  |  | Generic connector, single row, 01x02, script generated
SPI1,SPI2,SPI3,SPI4 | Conn_01x06_Socket | ~ | Connector_JST:JST_PH_B6B-PH-K_1x06_P2.00mm_Vertical | 4 |  | 97 |  |  |  |  |  |  | Generic connector, single row, 01x06, script generated
SW1 | Right angle Tact button | https://www.mouser.co.uk/datasheet/2/240/Littelfuse-3050591.pdf | Button_Switch_THT:SW_Tactile_SPST_Angled_PTS645Vx58-2LFS | 1 |  | 98 |  | PTS645VH58-2LFS | PTS645VH58-2LFS | CK |  | Right angle through hole Tact switch | Push button switch, generic, two pins
SW2,SW3,SW4 | SW_Push | ~ | Connector_PinHeader_2.54mm:PinHeader_1x02_P2.54mm_Vertical | 3 |  | 99 |  |  |  |  |  |  | Push button switch, generic, two pins
TP1,TP2,TP3,TP4,TP5,TP6,TP7,TP8,TP9,TP12,TP13,TP16 | TestPoint | ~ | TestPoint:TestPoint_Pad_D2.0mm | 12 |  | 100 |  |  |  |  |  |  | test point
U1 | AP22653W6 | https://www.diodes.com/assets/Datasheets/AP255x.pdf | Package_TO_SOT_SMD:SOT-23-6 | 1 |  | 101 | Digikey | 31-AP22653W6-7CT-ND | AP22653W6 | Diodes |  | Power Switch/Driver 1:1 P-Channel 2.1A SOT-23-6
U2 | RT9742SNGV | https://www.richtek.com/assets/product_file/RT9742/DS9742-10.pdf | Package_TO_SOT_SMD:TSOT-23 | 1 |  | 102 | Farnell | 2575555 | RT9742SNGV | RichTek | USWI00155 | Power Switch/Driver 1:1 N-Channel 500mA SOT-23-3
U3 | 74LVC1G07SE-7 | https://www.diodes.com/assets/Datasheets/74LVC1G07.pdf | Package_TO_SOT_SMD:SOT-353_SC-70-5 | 1 |  | 103 | Farnell | 2425492 | 74LVC1G07SE-7 | Diodes |  | Buffer, Non-Inverting 1 Element 1 Bit per Element Open Drain Output SOT-353
U4,U5,U10,U12,U14 | TPD4EUSB30 | http://www.ti.com/lit/ds/symlink/tpd2eusb30a.pdf | Package_SON:USON-10_2.5x1.0mm_P0.5mm | 5 |  | 104 | Farnell | 2335455 | CDDFN10-3324P-13 | Bourns | UDIO00346 | Quad TVS diode for high speed signals (USB3, GigE etc.)
U6 | BQ24650 | https://www.ti.com/lit/ds/symlink/bq24650.pdf | Package_DFN_QFN:Texas_RVA_VQFN-16-1EP_3.5x3.5mm_P0.5mm_EP2.14x2.14mm_ThermalVias | 1 |  | 105 |  |  |  |  |  |  | 10A, 28V max voltage, Battery Charger w/600kHz NMOS-NMOS Synchronous Buck Converter for Solar, VQFN-16
U7 | ASEK-32.768KHZ-L-R-T | https://abracon.com/Oscillators/ASEK.pdf | Crystal:Crystal_SMD_3225-4Pin_3.2x2.5mm | 1 |  | 106 |  | ASEK-32.768KHZ-L-R-T | ASEK-32.768KHZ-L-R-T | abracon |  | 32KHz Xtal oscilator
U8,U13 | FSUSB42MUX | https://www.onsemi.com/pub/Collateral/FSUSB42-D.PDF | Package_SO:MSOP-10_3x3mm_P0.5mm | 2 |  | 107 | Farnell | 2564479 | FSUSB42MUX | Onsemi |  | USB Switch IC 1 Channel 10-MSOP
U9 | AP22653W6 | https://www.diodes.com/assets/Datasheets/AP255x.pdf | Package_TO_SOT_SMD:SOT-23-6 | 1 |  | 108 | Digikey | AP2553W6-7DICT-ND | AP22653W6 | Diodes |  | Power Switch/Driver 1:1 P-Channel 2.1A SOT-23-6
U11 | USB2514B-I/M2 | http://ww1.microchip.com/downloads/en/DeviceDoc/00001692C.pdf | Package_DFN_QFN:QFN-36-1EP_6x6mm_P0.5mm_EP3.7x3.7mm | 1 |  | 109 | Farnell | 2775060 | USB2514B-I/M2 | Microchip | UICC00931 | USB Hub Controller USB Interface 36-SQFN (6x6) | USB 2.0 Hi-Speed Hub Controller
U15,U16,U17,U18,U19,U20,U21,U22,U23,U24,U25,U26,U27,U28,U29,U30 | INA226 | http://www.ti.com/lit/ds/symlink/ina226.pdf | Package_SO:VSSOP-10_3x3mm_P0.5mm | 16 |  | 110 |  |  |  |  |  |  | High-Side or Low-Side Measurement, Bi-Directional Current and Power Monitor (0-36V) with I2C Compatible Interface, VSSOP-10
U31,U33,U34 | AP64501SP-13 | https://www.diodes.com/assets/Datasheets/AP64501.pdf | Package_SO:SOIC-8-1EP_3.9x4.9mm_P1.27mm_EP2.95x4.9mm_Mask2.71x3.4mm_ThermalVias | 3 |  | 111 | Digikey | 31-AP64501SP-13CT-ND | AP64501SP-13 | Diodes |  | Buck Switching Regulator IC Positive Adjustable 0.8V 1 Output 5A 8-SOIC (0.154", 3.90mm Width) Exposed Pad
U32,U35,U40,U41,U42,U43,U44 | AP22815AWU | https://www.diodes.com/datasheet/download/AP22815_615.pdf | Package_TO_SOT_SMD:SOT-23-6 | 7 |  | 112 |  |  |  |  |  |  | Current limited power switch, single channel, 3.0V to 5.5V, 3A, SOT-23-6
U37 | CH343P |  | Package_DFN_QFN:QFN-16-1EP_3x3mm_P0.5mm_EP1.7x1.7mm_ThermalVias | 1 |  | 113
U38 | IP2721 | https://datasheet.lcsc.com/lcsc/2006111335_INJOINIC-IP2721_C603176.pdf | Package_SO:TSSOP-16_4.4x5mm_P0.65mm | 1 |  | 114 |  |  |  |  |  |  | USB TYPEC PD Controller Interface, TSSOP-16
U45,U46 | TCA9548APWR | http://www.ti.com/lit/ds/symlink/tca9548a.pdf | Package_SO:TSSOP-24_4.4x7.8mm_P0.65mm | 2 |  | 115 |  |  |  |  |  |  | Low voltage 8-channel I2C switch with reset, TSSOP-24
U47 | MCP3208 | http://ww1.microchip.com/downloads/en/DeviceDoc/21298c.pdf | Package_SO:SOIC-16_3.9x9.9mm_P1.27mm | 1 |  | 116 |  |  |  |  |  |  | A/D Converter, 12-Bit, 8-Channel, SPI Interface , 2.7V-5.5V
U52 | TB6612FNG | https://toshiba.semicon-storage.com/us/product/linear/motordriver/detail.TB6612FNG.html | Package_SO:SSOP-24_5.3x8.2mm_P0.65mm | 1 |  | 117 |  |  |  |  |  |  | Driver IC for Dual DC motor, SSOP-24
U53,U54 | MCP23S17_SO | http://ww1.microchip.com/downloads/en/DeviceDoc/20001952C.pdf | Package_SO:SSOP-28_3.9x9.9mm_P0.635mm | 2 |  | 118 |  |  |  |  |  |  | 16-bit I/O expander, SPI, interrupts, w pull-ups, SOIC-28
U55 | ICM-45686 |  | CM5IO:IC_ICM-45686 | 1 |  | 119 |  |  |  |  |  |  |  |  | TDK InvenSense | 0.86mm |  |  | 0.2 |  |  |  |  | Manufacturer Recommendations
U56 | BME280 | https://www.bosch-sensortec.com/media/boschsensortec/downloads/datasheets/bst-bme280-ds002.pdf | Package_LGA:Bosch_LGA-8_2.5x2.5mm_P0.65mm_ClockwisePinNumbering | 1 |  | 120 |  |  |  |  |  |  | 3-in-1 sensor, humidity, pressure, temperature, I2C and SPI interface, 1.71-3.6V, LGA-8
U57 | BNO080 |  | Package_LGA:LGA-28_5.2x3.8mm_P0.5mm | 1 |  | 121
U58 | MCP1541-TT | http://ww1.microchip.com/downloads/en/devicedoc/21653b.pdf | Package_TO_SOT_SMD:SOT-23 | 1 |  | 122 |  |  |  |  |  |  | 4.096V Voltage Reference, SOT-23
U65 | TPA6203A1DGN | https://www.ti.com/lit/ds/symlink/tpa6203a1.pdf | Package_SO:MSOP-8-1EP_3x3mm_P0.65mm_EP1.95x2.15mm_ThermalVias | 1 |  | 123 |  |  |  |  |  |  | 1.25W, Mono, Differential Audio Amplifier, MSOP-8
U67 | PCA9685PW | http://www.nxp.com/docs/en/data-sheet/PCA9685.pdf | Package_SO:TSSOP-28_4.4x9.7mm_P0.65mm | 1 |  | 124 |  |  |  |  |  |  | 16-channel 12-bit PWM Fm+ I2C-bus LED controller RGBA TSSOP
Y1 | 24MHz | ~ | Crystal:Crystal_SMD_HC49-SD | 1 |  | 125 | Farnell | 2508493 | X24M000000S128 | AEL |  | 24MHz Crystal 18pf 30ppm 30ppm | Two pin crystal
Y3 | 5MHz | ~ | Crystal:Crystal_SMD_HC49-SD | 1 |  | 126 |  |  |  |  |  |  | Two pin crystal
Y4 | 32.768MHz | ~ | Crystal:Crystal_SMD_HC49-SD | 1 |  | 127 | Farnell | 2508493 | X24M000000S128 | AEL |  | 24MHz Crystal 18pf 30ppm 30ppm | Two pin crystal
U48,U49,U50,U51 | TMC2240_SILENTSTEPSTICK |  | CM5IO:TMC2209 | 4 |  | 128 |  |  |  |  |  |  |  | https://www.snapeda.com/parts/TMC2209%20SILENTSTEPSTICK/Trinamic/view-part/?ref=eda | Trinamic Motion Control GmbH |  | Trinamic Motion Control GmbH | TMC2209 SILENTSTEPSTICK | 1.20 | None | TMC2209 Motor Controller/Driver Power Management Evaluation Board | None | TMC2209 SILENTSTEPSTICK | Manufacturer Recommendations |  |  |  | https://www.snapeda.com/parts/TMC2209%20SILENTSTEPSTICK/Trinamic/view-part/?ref=snap |  | In Stock
U64 | PCM2704CDBR |  | CM5IO:SSOP28 | 1 |  | 129 |  |  |  |  |  |  |  | https://www.snapeda.com/parts/PCM2704C/Texas+Instruments/view-part/?ref=eda |  |  | Texas Instruments | PCM2704C |  | None | Stereo Audio DAC with USB Interface, Single-Ended Headphone Output and S/PDIF Output | None |  |  |  |  |  | https://www.snapeda.com/parts/PCM2704C/Texas+Instruments/view-part/?ref=snap |  | In Stock
J1 | XT60-M |  | Connector_AMASS:AMASS_XT60-M_1x02_P7.20mm_Vertical | 1 |  | 130 |  |  |  |  |  |  |  | https://www.snapeda.com/parts/XT60-M/AMASS/view-part/?ref=eda | AMASS | 16.00 mm | AMASS | XT60-M | V1.2 | Package | Plug; DC supply; XT60; male; PIN: 2; for cable; soldered; 30A; 500V | None |  | IPC 7351B |  |  |  | https://www.snapeda.com/parts/XT60-M/AMASS/view-part/?ref=snap |  | Not in stock
U36,U39 | LTC3119EFE_PBF |  | CM5IO:SOP65P640X120-29N | 2 |  | 131 |  |  |  |  |  |  |  | https://www.snapeda.com/parts/LTC3119EFE%23PBF/Analog+Devices/view-part/?ref=eda | Analog Devices | 1.2mm | Analog Devices | LTC3119EFE#PBF | B | TSSOP-28 Linear Technology | Buck-Boost Switching Regulator IC Positive Adjustable 0.8V 1 Output 5A 28-TSSOP (0.173, 4.40mm Width) Exposed Pad | None |  | IPC-7351B |  |  |  | https://www.snapeda.com/parts/LTC3119EFE%23PBF/Analog+Devices/view-part/?ref=snap |  | In Stock
U59,U60,U61,U62,U66 | TS5A23157DGSR |  | CM5IO:SOP50P490X110-10N | 5 |  | 132 |  |  |  |  |  |  |  | https://www.snapeda.com/parts/TS5A23157DGSR/Texas+Instruments/view-part/?ref=eda | Texas Instruments | 1.1 mm | Texas Instruments | TS5A23157DGSR | F | VSSOP-10 Texas Instruments | 5-V, 2:1 (SPDT), 2-channel analog switch | None |  | IPC-7351B |  |  |  | https://www.snapeda.com/parts/TS5A23157DGSR/Texas+Instruments/view-part/?ref=snap |  | In Stock

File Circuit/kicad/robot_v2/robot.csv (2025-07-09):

Reference | Value | Datasheet | Footprint | Qty | DNP
C1,C12,C13,C14,C15,C22,C23,C24,C30,C31 | 100n | ~ | -- mixed values -- | 10
C2,C5 | 10u | ~ | Capacitor_SMD:C_0805_2012Metric | 2
C3,C7 | 100nf | ~ | Capacitor_SMD:C_0805_2012Metric | 2
C4 | 1uf | ~ | Capacitor_SMD:C_0805_2012Metric | 1
C6 | 100u | ~ | Capacitor_SMD:C_0805_2012Metric | 1
C8,C9 | 27pF | ~ | Capacitor_SMD:C_0805_2012Metric | 2
C10 | 100uf | ~ | Capacitor_SMD:C_0805_2012Metric | 1
C11,C21,C29 | 10u 35v | ~ | Capacitor_SMD:C_0805_2012Metric | 3
C16,C20,C28,C35 | 100uF | ~ | Capacitor_Tantalum_SMD:CP_EIA-7343-31_Kemet-D | 4
C17,C19,C25,C27,C32,C34,R4,R17,R18 | nf | ~ | -- mixed values -- | 9
C18,C26,C33 | 1.2nF | ~ | Capacitor_SMD:C_0805_2012Metric | 3
D1 | LED Red | ~ | LED_SMD:LED_0603_1608Metric | 1
D2 | LED Green | ~ | LED_SMD:LED_0603_1608Metric | 1
D3 | WS2812B | https://cdn-shop.adafruit.com/datasheets/WS2812B.pdf | LED_SMD:LED_WS2812B_PLCC4_5.0x5.0mm_P3.2mm | 1
D4,D6,D9 | LED | ~ |  | 3
J1,J3 | Conn_01x03 | ~ | Connector_PinHeader_2.54mm:PinHeader_1x03_P2.54mm_Vertical | 2
J2 | Conn_02x07_Odd_Even | ~ | Connector_PinHeader_2.54mm:PinHeader_2x07_P2.54mm_Vertical | 1
J4,J5,J15,J16 | Conn_01x22_Female | https://www.hirose.com/product/document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 | CM4IO:Hirose_FH12-22S-0.5SH_1x22-1MP_P0.50mm_Horizontal | 4
J6,J9 | THD-02-R | ~ | Connector_PinHeader_2.54mm:PinHeader_2x02_P2.54mm_Vertical | 2
J7 | Micro_SD_Card_Det | https://www.hirose.com/product/en/download_file/key_name/DM3/category/Catalog/doc_file_id/49662/?item_id=195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 | CM4IO:SDCARD_MOLEX_503398-1892 | 1
J8 | THD-20-R | ~ | Connector_PinHeader_2.54mm:PinHeader_2x20_P2.54mm_Vertical | 1
J10,J22 | 690-019-298-412 | https://en.wikipedia.org/wiki/HDMI | CM4IO:EDAC 690-019-298-412 | 2
J12 | 10018783-11200TLF | https://www.mouser.co.uk/datasheet/2/18/10018783-1525093.pdf | CM4IO:PCIex1-36 | 1
J13 | 690-008-221-904 | Conn USB Type A RCP 4/4 POS Solder RA Thru-Hole 8 Terminal 2 Port Tray | CM4IO:MOLEX_USB_67298-4090 | 1
J17 | Molex 470531000 | ~ | Connector:FanPinHeader_1x04_P2.54mm_Vertical | 1
J18 | Conn_01x12_Pin | ~ | Connector_PinHeader_2.54mm:PinHeader_1x12_P2.54mm_Vertical | 1
J19,J20,J23 | USB_C_Receptacle_USB2.0_16P | https://www.usb.org/sites/default/files/documents/usb_type-c.zip | Connector_USB:USB_C_Receptacle_Palconn_UTC16-G | 3
L1,L2,L3 | SRN6045TA-3R3Y | https://www.bourns.com/docs/Product-Datasheets/SRN6045TA.pdf | Inductor_SMD:L_Bourns_SRN6045TA | 3
Module1 | ComputeModule4 |  | CM4IO:Raspberry-Pi-4-Compute-Module | 1
Q1,Q2 | SS8050-G | https://www.onsemi.com/pub/Collateral/BC818-D.pdf | Package_TO_SOT_THT:TO-18-3_Lens | 2
R1,R10,R37,R38,R44 | 1k | ~ | Resistor_SMD:R_0805_2012Metric_Pad1.20x1.40mm_HandSolder | 5
R2,R3 | 470R | ~ | Resistor_SMD:R_0805_2012Metric_Pad1.20x1.40mm_HandSolder | 2
R5 | 0R | ~ | Resistor_SMD:R_0805_2012Metric_Pad1.20x1.40mm_HandSolder | 1
R6,R7,R8,R11,R28,R62,R63,R66,R67 | 2.2K 1% | ~ | Resistor_SMD:R_0805_2012Metric_Pad1.20x1.40mm_HandSolder | 9
R9,R22,R35 | 10R | ~ | Resistor_SMD:R_0805_2012Metric_Pad1.20x1.40mm_HandSolder | 3
R12,R13,R14,R16,R21 | 36K 1% | ~ | Resistor_SMD:R_0805_2012Metric_Pad1.20x1.40mm_HandSolder | 5
R15,R23,R25,R27,R29 | 12K 1% | ~ | Resistor_SMD:R_0805_2012Metric_Pad1.20x1.40mm_HandSolder | 5
R19,R31,R64,R65,R68,R69 | 5.1K 1% | ~ | Resistor_SMD:R_0805_2012Metric_Pad1.20x1.40mm_HandSolder | 6
R24 | 47K 1% | ~ | Resistor_SMD:R_0805_2012Metric_Pad1.20x1.40mm_HandSolder | 1
R26,R47,R48,R49,R50,R51,R52,R53,R54,R55,R56,R57,R58,R59,R60,R61 | 0.025Ω | ~ | Resistor_SMD:R_1020_2550Metric | 16
R30,R36 | 15K 1% | ~ | Resistor_SMD:R_0805_2012Metric_Pad1.20x1.40mm_HandSolder | 2
R39 | 33K 1% | ~ | Resistor_SMD:R_0805_2012Metric_Pad1.20x1.40mm_HandSolder | 1
R40,R41,R42,R43 | 10k | ~ | Resistor_SMD:R_0805_2012Metric_Pad1.20x1.40mm_HandSolder | 4
R45 | 13K 1% | ~ | Resistor_SMD:R_0805_2012Metric_Pad1.20x1.40mm_HandSolder | 1
R46 | 110K 1% | ~ | Resistor_SMD:R_0805_2012Metric_Pad1.20x1.40mm_HandSolder | 1
SW1 | SW_Push | ~ |  | 1
TH1,TH2 | Thermistor_NTC | ~ |  | 2
TP1,TP3,TP4,TP5,TP7 | TestPoint | ~ | TestPoint:TestPoint_Pad_1.0x1.0mm | 5
U1,U2,U4,U35,U39 | TPD4EUSB30 | http://www.ti.com/lit/ds/symlink/tpd2eusb30a.pdf | Package_SON:USON-10_2.5x1.0mm_P0.5mm | 5
U3 | MagJack-A70-112-331N126 | https://p.globalsources.com/IMAGES/PDT/SPEC/690/K1160305690.pdf | CM4IO:TRJG0926HENL | 1
U5,U9 | 74LVC1G07SE-7 | http://www.ti.com/lit/sg/scyt129e/scyt129e.pdf | Package_TO_SOT_SMD:SOT-353_SC-70-5 | 2
U6 | USB2514B-I/M2 | http://ww1.microchip.com/downloads/en/DeviceDoc/00001692C.pdf | Package_DFN_QFN:QFN-36-1EP_6x6mm_P0.5mm_EP3.7x3.7mm | 1
U7 | AP22653W6 | https://www.diodes.com/assets/Datasheets/AP255x.pdf | Package_TO_SOT_SMD:SOT-23-6 | 1
U8 | ESP32-S3-WROOM-2 | https://www.espressif.com/sites/default/files/documentation/esp32-s3-wroom-2_datasheet_en.pdf | RF_Module:ESP32-S3-WROOM-2 | 1
U10,U14,U16 | AP64501SP-13 | https://www.diodes.com/assets/Datasheets/AP64501.pdf | Package_SO:SOIC-8-1EP_3.9x4.9mm_P1.27mm_EP2.95x4.9mm_Mask2.71x3.4mm_ThermalVias | 3
U11 | EMC2301-1-ACZL-TR | https://ww1.microchip.com/downloads/en/DeviceDoc/2301.pdf | Package_SO:MSOP-8_3x3mm_P0.65mm | 1
U12 | RT9742SNGV | https://www.richtek.com/assets/product_file/RT9742/DS9742-09.pdf | Package_TO_SOT_SMD:SOT-23 | 1
U13,U38,U40 | FSUSB42MUX | https://www.onsemi.com/pub/Collateral/FSUSB42-D.PDF | Package_SO:MSOP-10_3x3mm_P0.5mm | 3
U15 | CH343P |  | Package_DFN_QFN:QFN-16-1EP_3x3mm_P0.5mm_EP1.7x1.7mm_ThermalVias | 1
U17,U19,U20,U21,U22,U23,U24,U25,U26,U27,U28,U29,U30,U31,U32,U33 | INA226 | http://www.ti.com/lit/ds/symlink/ina226.pdf | Package_SO:VSSOP-10_3x3mm_P0.5mm | 16
U18 | RT9742GGJ5 | https://www.richtek.com/assets/product_file/RT9742/DS9742-00.pdf | Package_TO_SOT_SMD:SOT-23-5 | 1
U34,U36 | ADS1115IDGS | http://www.ti.com/lit/ds/symlink/ads1113.pdf | Package_SO:TSSOP-10_3x3mm_P0.5mm | 2
U37,U41 | ADC1283 | https://www.st.com/resource/en/datasheet/adc1283.pdf | Package_SO:TSSOP-16_4.4x5mm_P0.65mm | 2
Y1 | 24MHz | ~ | Crystal:Crystal_SMD_HC49-SD | 1

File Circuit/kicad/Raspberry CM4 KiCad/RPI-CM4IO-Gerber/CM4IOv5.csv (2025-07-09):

Comment | Designator | Footprint
Battery_Cell | BT1 | BatteryHolder_Keystone_3034_1x20mm
100n | C1,C12,C13,C23,C7,C11,C14,C24,C22,C15,C57,C58,C40,C3,C4,C29,C62,C46 | C_0402_1005Metric
10u | C5,C47,C49,C51,C52,C10,C6,C20,C21,C19,C17,C33,C30,C32,C31,C2 | C_0805_2012Metric
100n 100v | C36 | C_0402_1005Metric
Conn_01x22_Female | J5,J16,J15,J4 | Hirose_FH12-22S-0.5SH_1x22-1MP_P0.50mm_Horizontal
Conn_01x03 | J1,J3 | PinHeader_1x03_P2.54mm_Vertical
1k | R10,R1 | R_0402_1005Metric
2.2K 1% | R11,R28,R6,R7,R8 | R_0402_1005Metric
36K 1% | R21,R16,R14,R13,R12 | R_0402_1005Metric
TPD4EUSB30 | U1,U2,U4 | USON-10_2.5x1.0mm_P0.5mm
RT9742SNGV | U12 | SOT-23
THD-20-R | J8 | PinHeader_2x20_P2.54mm_Vertical
Conn_02x05_Odd_Even | J14 | PinHeader_2x05_P2.54mm_Vertical
LED Green | D2 | LED_0603_1608Metric
EMC2301-1-ACZL-TR | U11 | MSOP-8_3x3mm_P0.65mm
27pF | C9,C8 | C_0402_1005Metric
24MHz | Y1 | Crystal_SMD_HC49-SD
74LVC1G07SE-7 | U14,U5,U9 | SOT-353_SC-70-5
USB2514B-I/M2 | U6 | QFN-36-1EP_6x6mm_P0.5mm_EP3.7x3.7mm
510K 1% | R20,R19 | R_0402_1005Metric
12K 1% | R15,R26,R27,R23,R29 | R_0402_1005Metric
470R | R3,R2 | R_0402_1005Metric
THD-02-R | J9,J6 | PinHeader_2x02_P2.54mm_Vertical
USB_OTG | J11 | USB_Micro-B_EDAC_UCON00686
LED Red | D1 | LED_0603_1608Metric
RT9742GGJ5 | U18 | SOT-23-5
Barrel_Jack | J19 | BarrelJack_Horizontal
MagJack-A70-112-331N126 | U3 | TRJG0926HENL
690-019-298-412 | J10,J22 | EDAC 690-019-298-412
15K 1% | R36,R30 | R_0402_1005Metric
AP22653W6 | U7 | SOT-23-6
FSUSB42MUX | U13 | MSOP-10_3x3mm_P0.5mm
690-008-221-904 | J13 | MOLEX_USB_67298-4090
Molex 470531000 | J17 | FanPinHeader_1x04_P2.54mm_Vertical
MountingHole | H1,H2,H3,H4,H5,H6,H7,H8 | MountingHole_2.7mm_M2.5
MMBZ5242BLT3G | D4 | D_SOT-23_ANK
nf | C59,C61,C65,C63 | C_0402_1005Metric
1.2nF | C60,C64 | C_0402_1005Metric
SRN6045TA-3R3Y | L5,L3 | L_Bourns_SRN6045TA
10R | R9,R22 | R_0402_1005Metric
AP64501SP-13 | U16 | SOIC-8-1EP_3.9x4.9mm_P1.27mm
20K 1% | R25 | R_0402_1005Metric
AMP171826-4 | J20 | TE_171826-4
Conn_02x07_Odd_Even | J2 | PinHeader_2x07_P2.54mm_Vertical
nf | R4 | R_0805_2012Metric_Pad1.15x1.40mm_HandSolder
0R | R5 | R_0805_2012Metric_Pad1.15x1.40mm_HandSolder
BAT54C-7-F | D3 | SOT-23
PCF85063AT/AAZ | U8 | SOIC-8_3.9x4.9mm_P1.27mm
X32K768S301 | Y2 | Crystal_SMD_3215-2Pin_3.2x1.5mm
Micro_SD_Card_Det | J7 | SDCARD_MOLEX_503398-1892
DMP3013SFV-7 | Q1 | Diodes_PowerDI3333-8
47K 1% | R24 | R_0402_1005Metric
AP64501SP-13 | U15 | SOIC-8-1EP_3.9x4.9mm_P1.27mm
10018783-11200TLF | J12 | PCIex1-36
100uF | C16,C18,C45 | CP_EIA-7343-31_Kemet-D
10u 35v | C34,C35,C37,C38,C39,C41,C25,C26,C27,C28,C43,C44,C42 | C_0805_2012Metric
nf | R17,R18 | R_0402_1005Metric
ComputeModule4 | Module1 | Raspberry-Pi-4-Compute-Module
TestPoint | TP1,TP2,TP6,TP4,TP3,TP5 | TestPoint_Pad_2.0x2.0mm

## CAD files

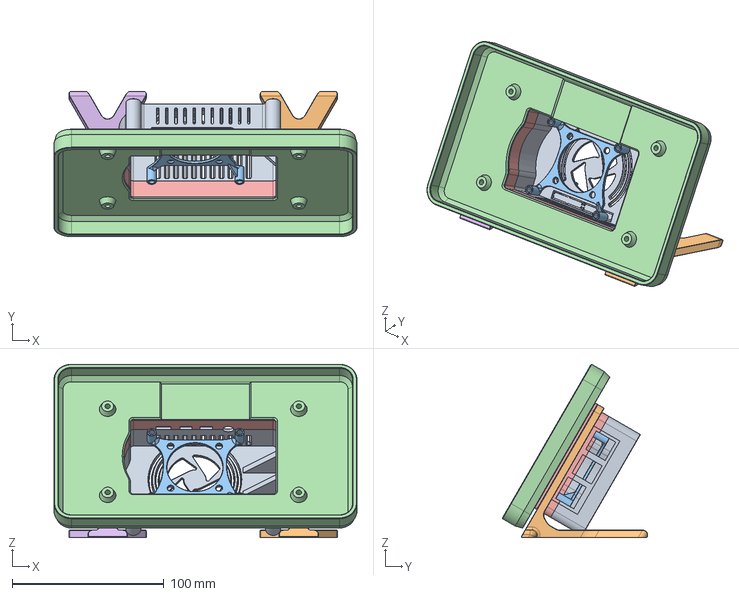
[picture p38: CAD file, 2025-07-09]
Robot 3d/Raspberry pi 7_ Display Stand/cad/rpi4-case_asm.stp
200.0 x 95.9 x 114.4 mm

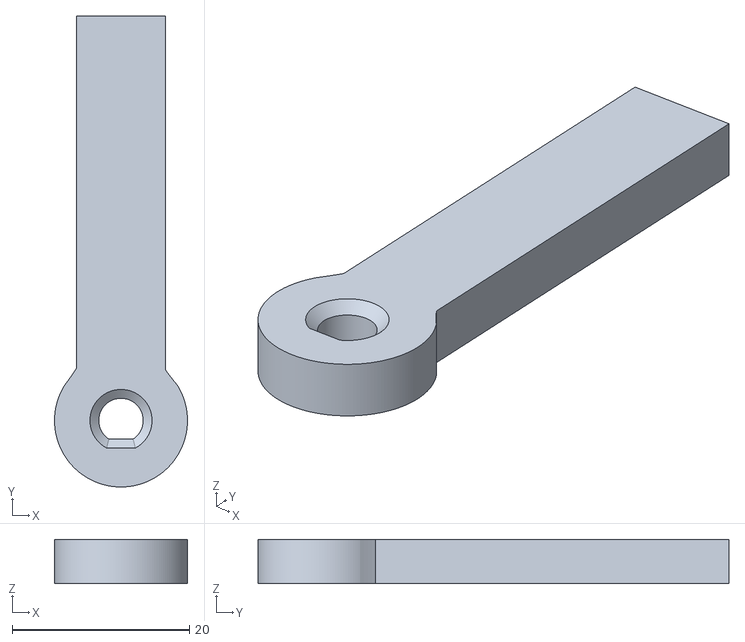
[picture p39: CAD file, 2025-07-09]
Robot 3d/basic/Stepper Flag.stl
15.0 x 53.1 x 5.00

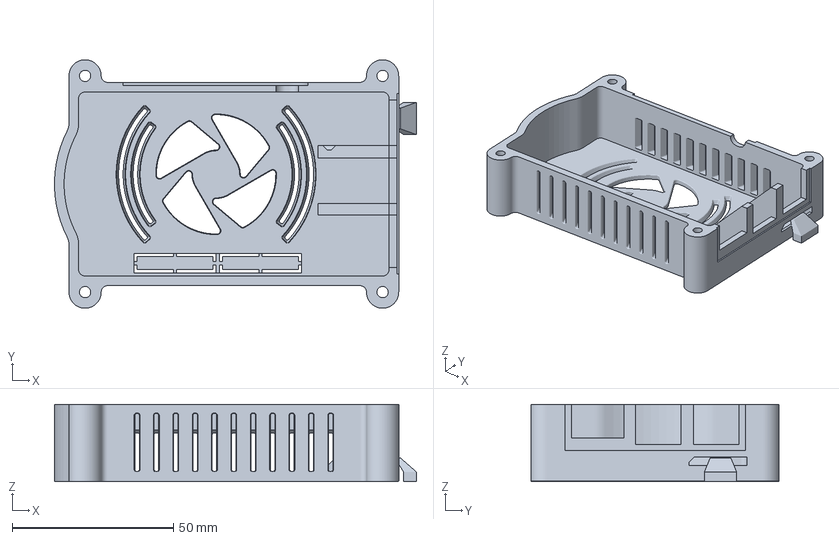
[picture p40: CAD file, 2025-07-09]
Robot 3d/Raspberry pi 7_ Display Stand/case top v2/rpi4-case-top_v2.3mf
112.2 x 77.0 x 24.0 mm

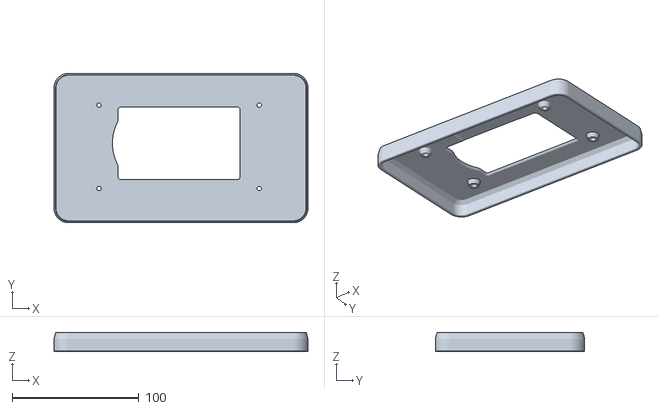
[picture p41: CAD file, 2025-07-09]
Robot 3d/Raspberry pi 7_ Display Stand/rpi4-display-case.stl
200.0 x 117.7 x 15.0

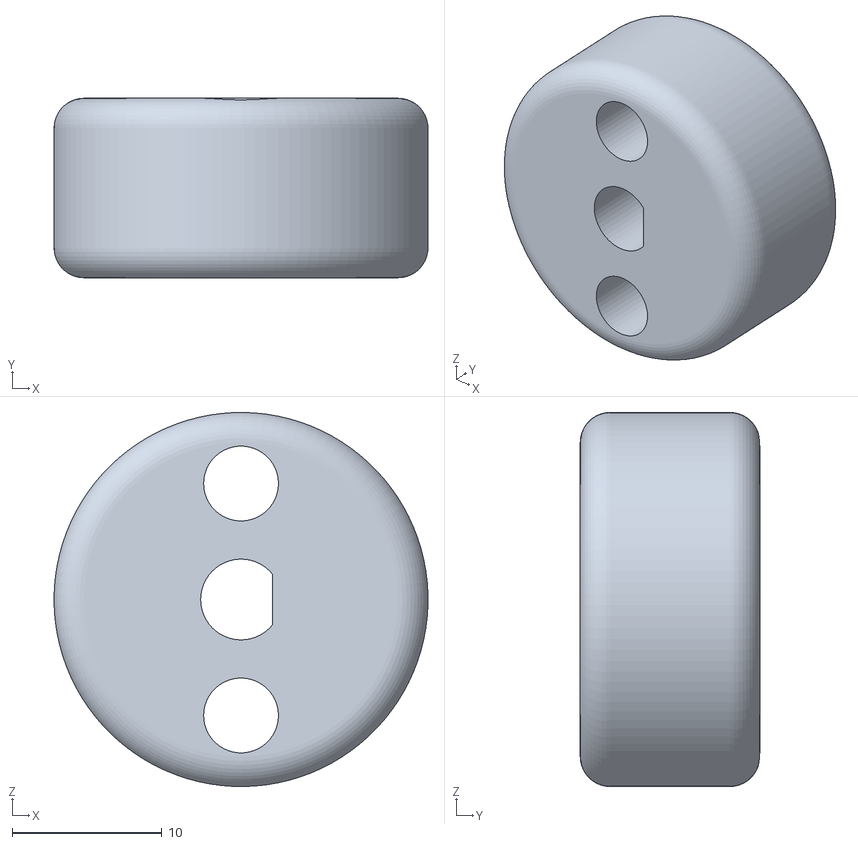
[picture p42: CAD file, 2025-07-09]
Robot 3d/szekér/lego_wheel_to_stepper_adapter.stl
25.0 x 12.0 x 25.0

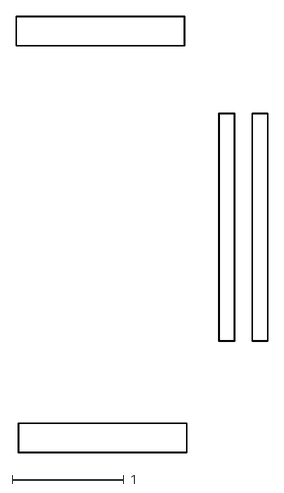
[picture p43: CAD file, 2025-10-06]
Circuit/kicad/V4/szalagkábel/szalagkábel-F_Courtyard.dxf
2.26 x 3.91

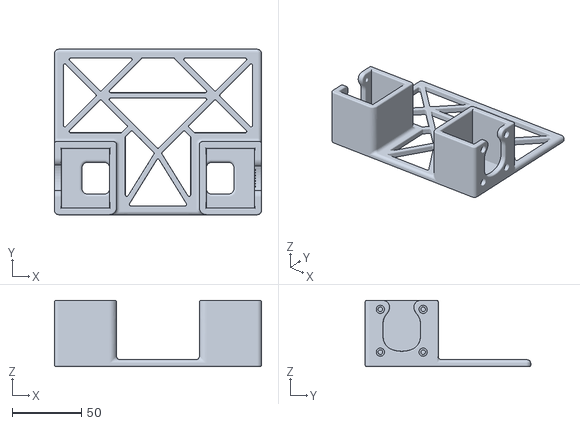
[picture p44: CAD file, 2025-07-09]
Robot 3d/szekér/robot_0.1.stl
150.0 x 120.0 x 48.0

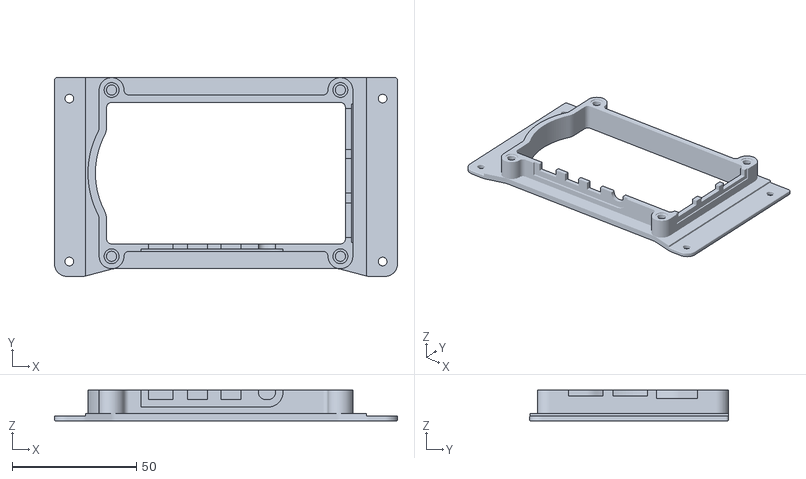
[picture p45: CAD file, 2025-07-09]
Robot 3d/Raspberry pi 7_ Display Stand/rpi4-case-bottom.stl
138.2 x 80.1 x 12.4

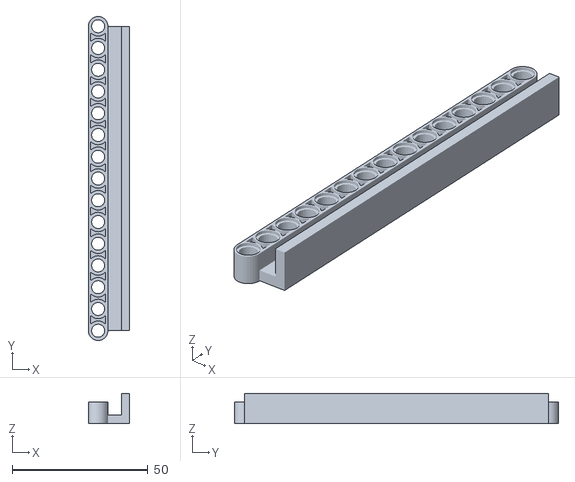
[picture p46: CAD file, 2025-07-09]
Robot 3d/szekér/15 pin LEGO for robot_0.1.stl
15.2 x 119.2 x 11.1

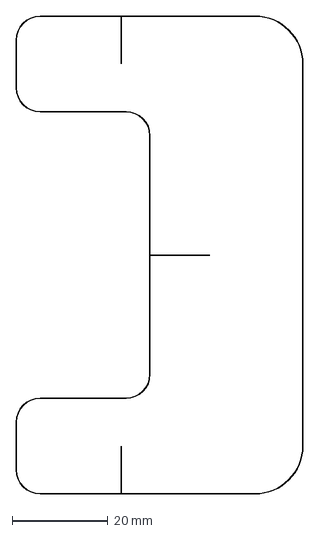
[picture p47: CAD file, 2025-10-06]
Circuit/kicad/V4/szalagkábel/szalagkábel-F_Courtyard v2.2.dxf
60.0 x 100.0 mm

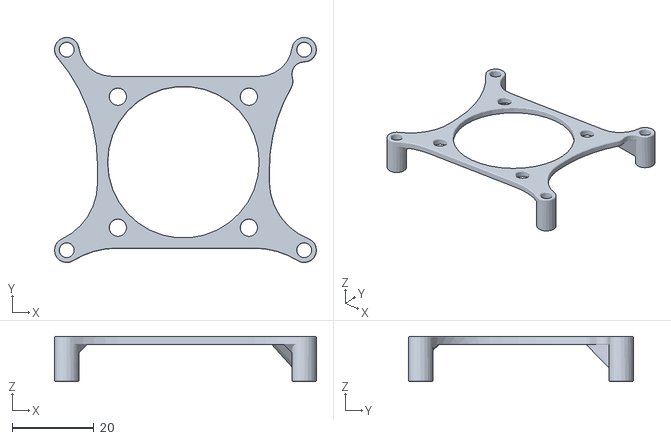
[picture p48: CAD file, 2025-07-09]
Robot 3d/Raspberry pi 7_ Display Stand/rpi4-fanmount.stl
64.0 x 55.0 x 11.0

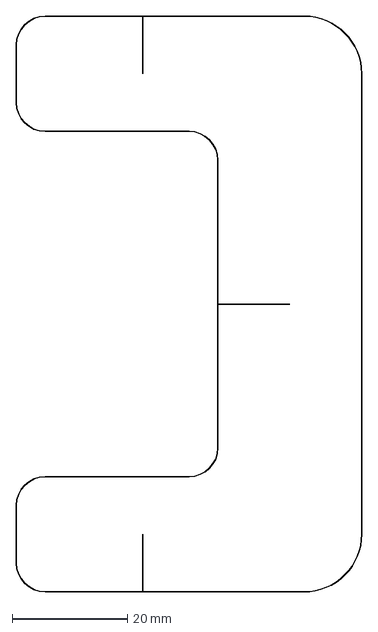
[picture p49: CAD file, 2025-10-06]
Circuit/kicad/V4/szalagkábel/v2_körvonal.dxf
60.0 x 100.0 mm

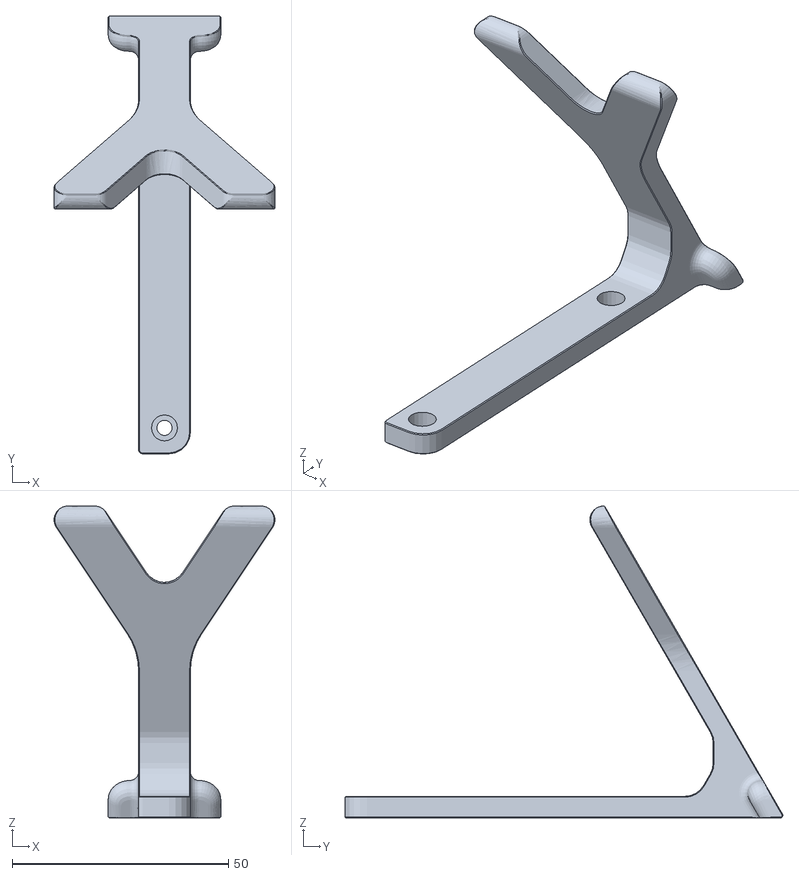
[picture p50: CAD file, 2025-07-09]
Robot 3d/Raspberry pi 7_ Display Stand/rpi4-stand-right.stl
51.0 x 101.1 x 72.1

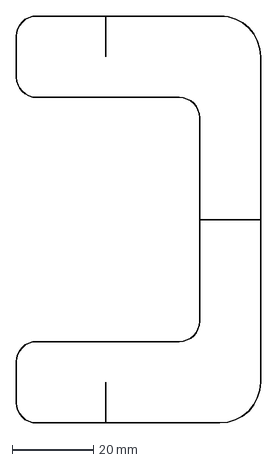
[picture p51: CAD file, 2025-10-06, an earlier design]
Circuit/kicad/V4/szalagkábel/v1_körvonal.dxf
60.0 x 100.0 mm

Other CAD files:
Robot 3d/Raspberry pi 7_ Display Stand/case top v2/rpi4-case_asm_v2.stp
Robot 3d/Raspberry pi 7_ Display Stand/rpi4-case-top.stl
Robot 3d/Raspberry pi 7_ Display Stand/rpi4-stand-left.stl
Circuit/kicad/V4/szalagkábel/szalagkábel-F_Courtyard v2_1.dxf
Circuit/kicad/V4/szalagkábel/szalagkábel-F_Courtyard v2.f3d
Circuit/kicad/V4/szalagkábel/szalagkábel-F_Courtyard v2_1.f3d
Robot 3d/Raspberry pi 7_ Display Stand/case top v2/rpi4-case-top_v2.stl

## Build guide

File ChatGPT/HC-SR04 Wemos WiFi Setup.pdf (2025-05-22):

# HC-SR04 Wemos WiFi Setup

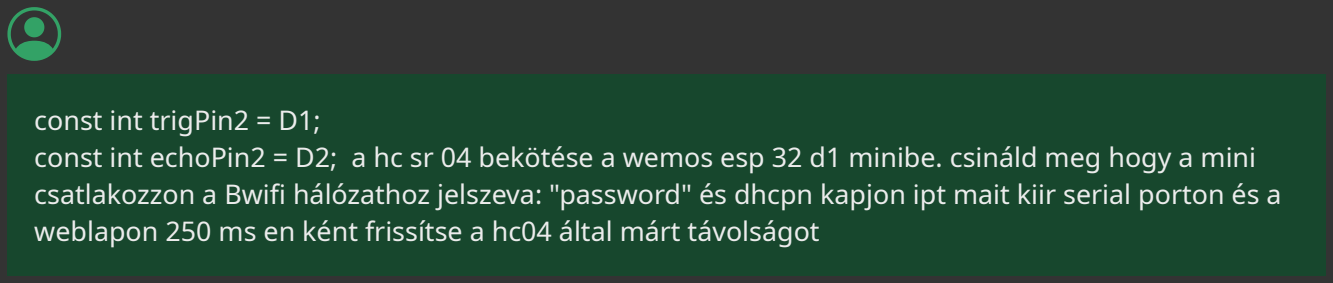
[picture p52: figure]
const int trigPin2 = D1;

const int echoPin2 = D2; a hc sr 04 bekötése a wemos esp 32 d1 minibe. csináld meg hogy a mini csatlakozzon a Bwifi hálózathoz jelszeva: "password" és dhcpn kapjon ipt mait kiir serial porton és a weblapon 250 ms en ként frissítse a hc04 által márt távolságot

Az alábbi példa megmutatja, hogyan csatlakoztasd a HC-SR04 ultrahangos szenzort a Wemos D1 Mini ESP32-re, majd csatlakoztasd a `Bwifi` nevű WiFi hálózathoz jelszóval `password`, és jelenítsd meg a távolságot:

a soros porton
egy weboldalon, 250 ms-onként frissítve az értéket.

🧠 Hardver bekötés (Wemos D1 Mini ESP32):

HC-SR04 | ESP32 (D1 Mini)
VCC | 5V
GND | GND
Trig | D1 (GPIO5)
Echo | D2 (GPIO4)

✅ Arduino kód:

cpp

#include <WiFi.h>

#include <WebServer.h>

const char* ssid = "Bwifi";
const char* password = "password";

const int trigPin = 5; // D1 = GPIO5 const int echoPin = 4; // D2 = GPIO4

WebServer server(80);
long duration;
float distance;
unsigned long lastUpdate = 0;
const unsigned long updateInterval = 250;

void setup() {
Serial.begin(115200);
pinMode(trigPin, OUTPUT);
pinMode(echoPin, INPUT);

// WiFi kapcsolat
WiFi.begin(ssid, password); Serial.print("Csatlakozás a WiFi-hez");
while (WiFi.status() != WL_CONNECTED) {
delay(500);
Printed using ChatGPT to PDF, (https://pdfcrowd.com/chatgpt-to-pdf/?ref=chatgpt) powered by PDFCrowd HTML to PDF API. (https://pdfcrowd.com/api/html-to-pdf-api/?ref=chatgpt) | 1/24

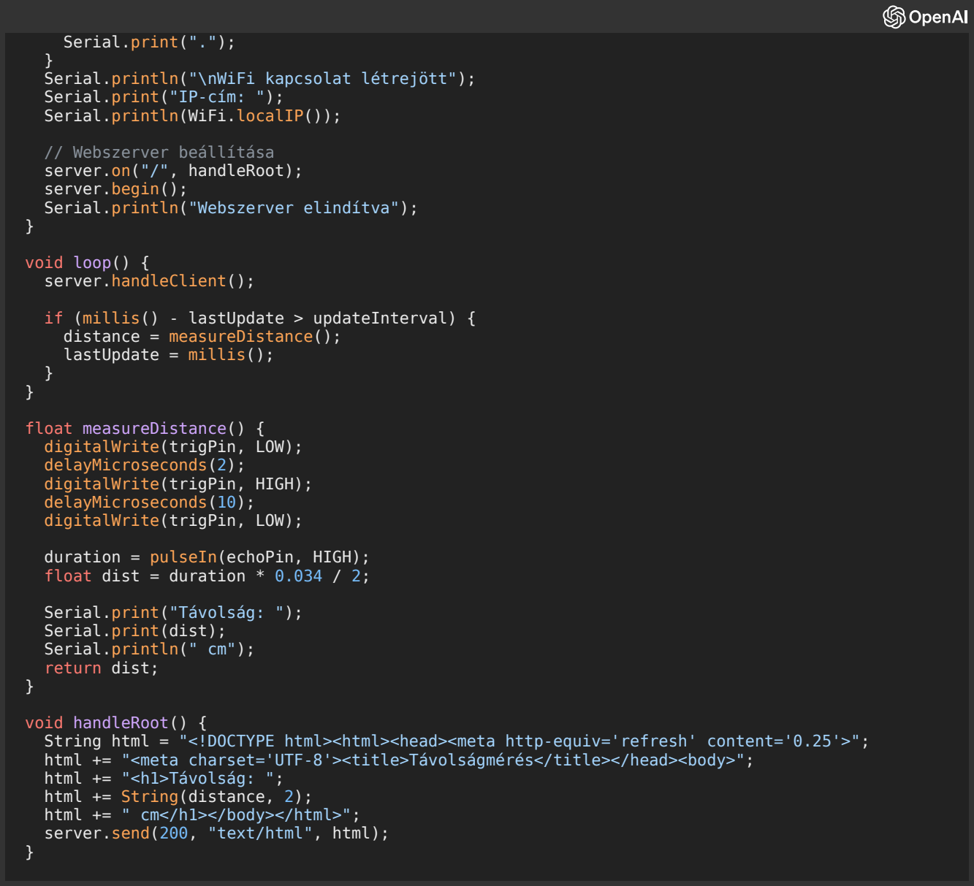
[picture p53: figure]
Serial.print(".");; } Serial.println("\nWiFi kapcsolat létrejött"); Serial.print("IP-cím: "); Serial.println(WiFi.localIP());; // Webszerver beállítása server.on("/", handleRoot); server.begin(); Serial.println("Webszerver elindítva");; void loop() { server.handleClient();; distance = measureDistance(); lastUpdate = millis();; float measureDistance() { digitalWrite(trigPin, LOW); delayMicroseconds(2); digitalWrite(trigPin, HIGH); delayMicroseconds(10); digitalWrite(trigPin, LOW);; duration = pulseIn(echoPin, HIGH); float dist = duration * 0.034 / 2;; Serial.print("Távolság: ")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

if (millis() - lastUpdate > updateInterval) {

String html = "<!DOCTYPE html><html><head><meta http-equiv='refresh' content='0.25'>";

️ Megjegyzések:

A HTML oldal 250 ms-onként automatikusan frissül (`<meta http-equiv='refresh' content='0.25'>`). A távolság mérés is 250 ms időközönként frissül a `loop()` függvényben.

Ha szeretnél AJAX-os megoldást automata frissítésre anélkül, hogy újratöltené az egész oldalt, jelezd, és

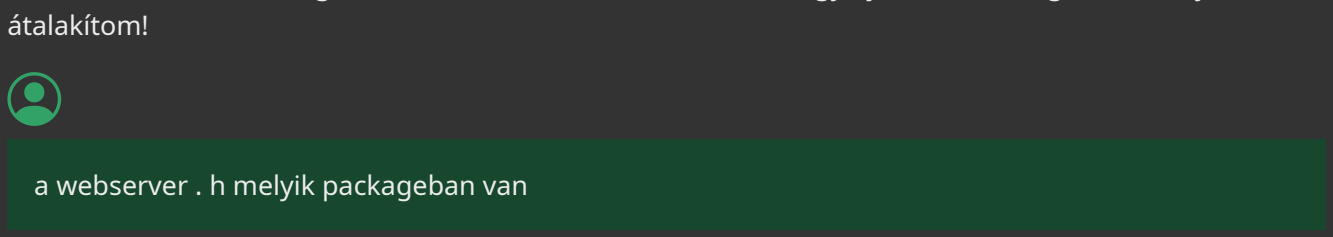
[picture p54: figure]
átalakítom!; a webserver . h melyik packageban van

A `WebServer.h` az ESP32 esetén a következő könyvtárban található:
📦 Könyvtár:
Printed using ChatGPT to PDF, (https://pdfcrowd.com/chatgpt-to-pdf/?ref=chatgpt) powered by PDFCrowd HTML to PDF API. (https://pdfcrowd.com/api/html-to-pdf-api/?ref=chatgpt) | 2/24

Ez a `WebServer` osztály az ESP32-hez tartozó alapértelmezett Arduino könyvtár része, és az alábbi csomagban található:

📚 ESP32 Arduino Core
Telepítéshez:
Arduino IDE-ben →
Eszközök > Kártya > Kártyakezelő > ESP32 → Telepítsd:

`esp32 by Espressif Systems`

✅ Telepítési lépések Arduino IDE-ben:

1. Menj a "Eszközök > Kártya > Kártyakezelő…" menüpontra.

### 2. Keresd meg: `esp32`

3. Telepítsd az "esp32 by Espressif Systems" csomagot.
4. Ezután válaszd ki a megfelelő táblát: `WEMOS D1 MINI ESP32` vagy `ESP32 Dev Module`.

🧪 Ellenőrzés:

Miután telepítetted, ez a fájl elérhető lesz:

bash

<Arduino sketchbook folder>/packages/esp32/hardware/esp32/.../libraries/WebServer/src/WebServer.h

🔧 Ha PlatformIO-t használsz:
A `WebServer` automatikusan elérhető az `esp32` platformmal. A `platformio.ini` fájlban ez lehet például:

ini

[env:esp32dev]
platform = espressif32
board = esp32dev
framework = arduino

Ha szeretnéd, segítek automatikusan beállítani a PlatformIO vagy Arduino IDE környezetet ehhez a

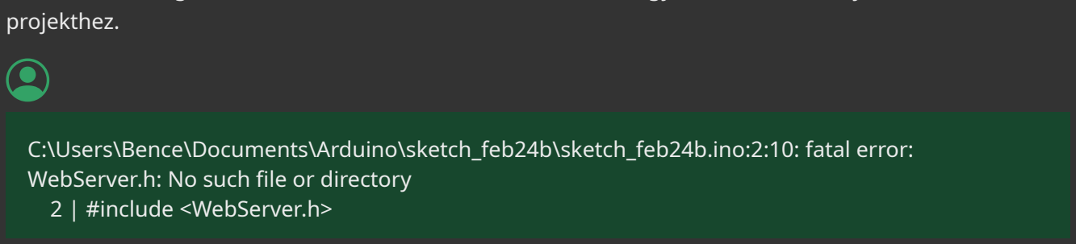
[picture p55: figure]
projekthez.; C:\Users\Bence\Documents\Arduino\sketch_feb24b\sketch_feb24b.ino:2:10: fatal error: WebServer.h: No such file or directory 2 | #include <WebServer.h>

Printed using ChatGPT to PDF, (https://pdfcrowd.com/chatgpt-to-pdf/?ref=chatgpt) powered by PDFCrowd HTML to PDF API. (https://pdfcrowd.com/api/html-to-pdf-api/?ref=chatgpt) | 3/24

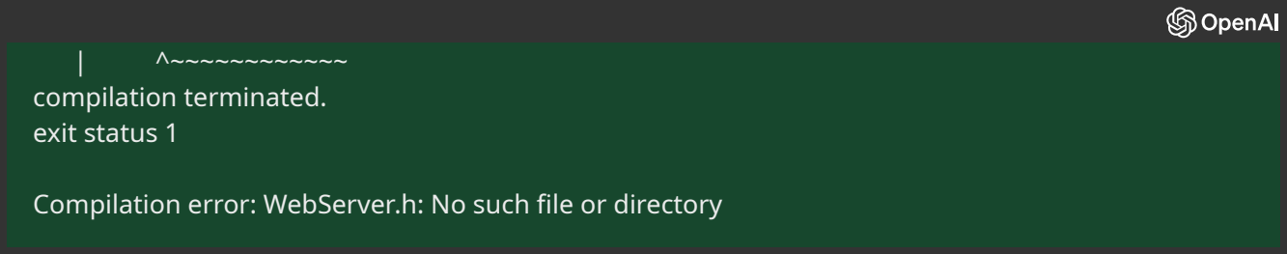
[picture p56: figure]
compilation terminated. exit status 1

Compilation error: WebServer.h: No such file or directory

Ez a hiba azt jelenti, hogy az `WebServer.h` fájlt nem találja az Arduino fordító — valószínűleg azért, mert:

Nem a megfelelő ESP32 kártya van kiválasztva, VAGY
Nem az ESP32, hanem az ESP8266 kártya van kiválasztva.

✅ Megoldás lépésenként

1. 📥 Telepítsd az ESP32 board támogatást

### 1. Arduino IDE-ben menj ide: Eszközök > Kártya > Kártyakezelő… 2. A keresőmezőbe írd be: `esp32`

### 3. Telepítsd: `esp32 by Espressif Systems`

4. Várd meg a telepítést.
2. ✅ Válaszd ki a megfelelő ESP32 kártyát

Menj ide:
Eszközök > Kártya és válaszd ki:

`WEMOS D1 MINI ESP32`
vagy
`ESP32 Dev Module` (ez is működik, ha az előbbi nincs)
3. 🔁 Indítsd újra az Arduino IDE-t

Ezután próbáld újra lefordítani a programot.

ℹ️ Fontos megjegyzés

Az `ESP8266` használ `ESP8266WebServer.h`-t

Az `ESP32` használ `WebServer.h`-t

Tehát ha véletlenül az ESP8266 kártya van kiválasztva, de `WebServer.h`-t próbálsz használni, ez a hiba jön elő.

Ha nem vagy biztos benne, melyik kártya van kiválasztva, kérlek másold ide a `Tools > Board` menüpont beállításaidat, és megnézem.

Printed using ChatGPT to PDF, (https://pdfcrowd.com/chatgpt-to-pdf/?ref=chatgpt) powered by PDFCrowd HTML to PDF API. (https://pdfcrowd.com/api/html-to-pdf-api/?ref=chatgpt) | 4/24

Köszönöm a pontosítást! Mivel ESP8266-od van (pl. Wemos D1 Mini ESP8266), a `WebServer.h` nem fog működni — helyette az ESP8266 saját könyvtárát kell használnod:

✅ A helyes include:

cpp

#include <ESP8266WiFi.h>

#include <ESP8266WebServer.h>

🔁 Átdolgozott kód ESP8266-ra:

cpp

#include <ESP8266WiFi.h>

#include <ESP8266WebServer.h>

const char* ssid = "Bwifi"; const char* password = "password";

const int trigPin = D1;
const int echoPin = D2;

ESP8266WebServer server(80); long duration;
float distance;
unsigned long lastUpdate = 0;
const unsigned long updateInterval = 250;

void setup() {
Serial.begin(115200);
pinMode(trigPin, OUTPUT);
pinMode(echoPin, INPUT);

WiFi.begin(ssid, password); Serial.print("Csatlakozás a WiFi-hez"); while (WiFi.status() != WL_CONNECTED) { delay(500);
Serial.print(".");
}
Serial.println("\nWiFi kapcsolat létrejött"); Serial.print("IP-cím: ");
Serial.println(WiFi.localIP());

server.on("/", handleRoot);
server.begin();
Serial.println("Webszerver elindítva"); }

void loop() {
server.handleClient();

if (millis() - lastUpdate > updateInterval) { distance = measureDistance();
lastUpdate = millis();
}
}

float measureDistance() {
digitalWrite(trigPin, LOW);
delayMicroseconds(2);
digitalWrite(trigPin, HIGH);
Printed using ChatGPT to PDF, (https://pdfcrowd.com/chatgpt-to-pdf/?ref=chatgpt) powered by PDFCrowd HTML to PDF API. (https://pdfcrowd.com/api/html-to-pdf-api/?ref=chatgpt) | 5/24

delayMicroseconds(10);
digitalWrite(trigPin, LOW);

duration = pulseIn(echoPin, HIGH); float dist = duration * 0.034 / 2;

Serial.print("Távolság: "); Serial.print(dist);
Serial.println(" cm");
return dist;
}

void handleRoot() {
String html = "<!DOCTYPE html><html><head><meta http-equiv='refresh' content='0.25'>"; html += "<meta charset='UTF-8'><title>Távolságmérés</title></head><body>";
html += "<h1>Távolság: ";
html += String(distance, 2);
html += " cm</h1></body></html>";
server.send(200, "text/html", html); }

🔧 Ne felejtsd:

A kártyánál válaszd ki: Wemos D1 R1, Wemos D1 Mini, vagy NodeMCU 1.0 (ESP8266-alapú modul) A `pulseIn()` megbízhatósága függ a vezeték hosszától és zavaroktól. Lehet érdemes szoftveres timeoutot is hozzáadni, ha később fagyásokat tapasztalsz.

Szükséged van AJAX-alapú webes frissítésre is, vagy jó ez az automatikus újratöltős verzió?

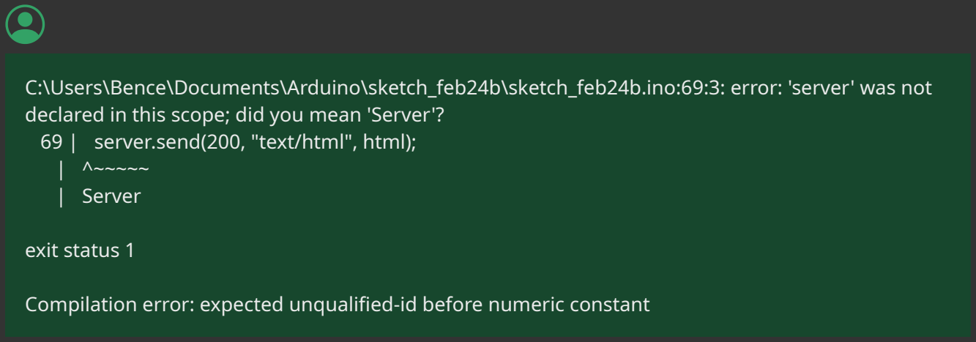
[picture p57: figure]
C:\Users\Bence\Documents\Arduino\sketch_feb24b\sketch_feb24b.ino:69:3: error: 'server' was not; 69 | server.send(200, "text/html", html); | ^~~~~~ | Server; exit status 1

declared in this scope; did you mean 'Server'?

Compilation error: expected unqualified-id before numeric constant

Ez a hiba valószínűleg nevet ütköztet, méghozzá a `server` azonosítóval. Mivel az ESP8266 könyvtárban már létezhet `Server` néven valami más definíció, a `server` változó neve ütközhet ezzel.

✅ Megoldás: nevezd át `server`-t pl. `webServer`-re

Íme az átnevezett, javított kód:

cpp

#include <ESP8266WiFi.h>

#include <ESP8266WebServer.h>

const char* ssid = "Bwifi";
const char* password = "password";

const int trigPin = D1;
Printed using ChatGPT to PDF, (https://pdfcrowd.com/chatgpt-to-pdf/?ref=chatgpt) powered by PDFCrowd HTML to PDF API. (https://pdfcrowd.com/api/html-to-pdf-api/?ref=chatgpt) | 6/24

const int echoPin = D2;

ESP8266WebServer webServer(80); // <-- itt átneveztük! long duration;
float distance;
unsigned long lastUpdate = 0;
const unsigned long updateInterval = 250;

void setup() {
Serial.begin(115200);
pinMode(trigPin, OUTPUT);
pinMode(echoPin, INPUT);

WiFi.begin(ssid, password); Serial.print("Csatlakozás a WiFi-hez"); while (WiFi.status() != WL_CONNECTED) { delay(500);
Serial.print(".");
}
Serial.println("\nWiFi kapcsolat létrejött"); Serial.print("IP-cím: ");
Serial.println(WiFi.localIP());

webServer.on("/", handleRoot); // <-- frissítve
webServer.begin(); | // <-- frissítve
Serial.println("Webszerver elindítva");
}

void loop() {
webServer.handleClient(); | // <-- frissítve

if (millis() - lastUpdate > updateInterval) { distance = measureDistance();
lastUpdate = millis();
}
}

float measureDistance() {
digitalWrite(trigPin, LOW); delayMicroseconds(2);
digitalWrite(trigPin, HIGH); delayMicroseconds(10);
digitalWrite(trigPin, LOW);

duration = pulseIn(echoPin, HIGH); float dist = duration * 0.034 / 2;

Serial.print("Távolság: "); Serial.print(dist);
Serial.println(" cm");
return dist;
}

void handleRoot() {
String html = "<!DOCTYPE html><html><head><meta http-equiv='refresh' content='0.25'>"; html += "<meta charset='UTF-8'><title>Távolságmérés</title></head><body>";
html += "<h1>Távolság: ";
html += String(distance, 2);
html += " cm</h1></body></html>";
webServer.send(200, "text/html", html); // <-- frissítve }

💡 Összefoglalva:

A `server` változónév ütközhetett beépített névvel vagy más könyvtárral. Átneveztük `webServer`-re, hogy elkerüljük az ütközést.

Most már fordulnia és működnie kell az ESP8266-on.

Printed using ChatGPT to PDF, (https://pdfcrowd.com/chatgpt-to-pdf/?ref=chatgpt) powered by PDFCrowd HTML to PDF API. (https://pdfcrowd.com/api/html-to-pdf-api/?ref=chatgpt) | 7/24

Ha szeretnéd, megmutatom, hogyan tudod AJAX-szal szépen frissíteni az értéket reloading nélkül is.

Ha a soros porton vagy a weboldalon csak pontokat (`.`) jelennek meg, akkor az azt jelenti, hogy az ESP8266 nem tud csatlakozni a WiFi hálózathoz.

🔍 Mi történik?

A kódban van ez a rész:

cpp

while (WiFi.status() != WL_CONNECTED) { delay(500);
Serial.print(".");
}

Ez addig ír ki pontokat, amíg nem jön létre WiFi kapcsolat. Tehát, ha csak pontokat látsz, akkor a WiFi kapcsolat sikertelen.

✅ Ellenőrizendők:

1. 📶 SSID és jelszó helyes?

Győződj meg róla, hogy ezt a két értéket helyesen adtad meg:

cpp

const char* ssid = "Bwifi"; // A hálózat neve
const char* password = "password"; // A jelszó

➡️ Ha bármelyik el van írva (pl. kis- és nagybetű nem stimmel), nem fog csatlakozni!

2. 🌐 A router engedi az ESP8266-ot csatlakozni?

Bizonyos routerek tiltják az ismeretlen eszközöket.
Próbáld ki a telefonod hotspotját:
Hozz létre hotspotot pl. `Bwifi` néven, `password` jelszóval. Így ki tudod zárni, hogy a routerrel van a gond.
3. 📡 A WiFi jelerősség gyenge?

Ha a Wemos D1 Mini túl messze van a routertől, a kapcsolat nem fog sikerülni.
Próbáld meg közelebb hozni.
Printed using ChatGPT to PDF, (https://pdfcrowd.com/chatgpt-to-pdf/?ref=chatgpt) powered by PDFCrowd HTML to PDF API. (https://pdfcrowd.com/api/html-to-pdf-api/?ref=chatgpt) | 8/24

4. 📲 SSID rejtett?

Ha a WiFi hálózat rejtett (hidden), az ESP8266 nem találja meg. Ebben az esetben: Állítsd be a routert, hogy a WiFi ne legyen rejtett (legalább ideiglenesen).

🧪 Teszt: Kapcsolódik-e?

Próbáld meg ideiglenesen ezt a tesztkódot:

cpp

#include <ESP8266WiFi.h>

const char* ssid = "Bwifi"; const char* password = "password";

void setup() {
Serial.begin(115200);
WiFi.begin(ssid, password); Serial.print("Csatlakozás a WiFi-hez");

while (WiFi.status() != WL_CONNECTED) { delay(500);
Serial.print(".");
}

Serial.println("");
Serial.println("WiFi kapcsolat létrejött!"); Serial.print("IP-cím: ");
Serial.println(WiFi.localIP());
}

void loop() {
}

➡️ Ha ez a tesztkód még mindig csak pontokat ír, akkor a hiba biztosan a hálózat beállításaiban van (nem szoftveres).

Ha szeretnéd, segítek újra konfigurálni a routert vagy teszt-hálózatot beállítani, csak írd meg, mire van lehetőséged.

csatlakozik a wifihez kap ipt de nem érem elC:\Users\Bence>ping 192.168.0.69

Pinging 192.168.0.69 with 32 bytes of data:
Request timed out.
Request timed out.
Request timed out.
Request timed out.

Ping statistics for 192.168.0.69: Távolság: 192.168.0.69

### 7.68 cm

Távolság: 192.168.0.69

### 7.68 cm

Printed using ChatGPT to PDF, (https://pdfcrowd.com/chatgpt-to-pdf/?ref=chatgpt) powered by PDFCrowd HTML to PDF API. (https://pdfcrowd.com/api/html-to-pdf-api/?ref=chatgpt) | 9/24

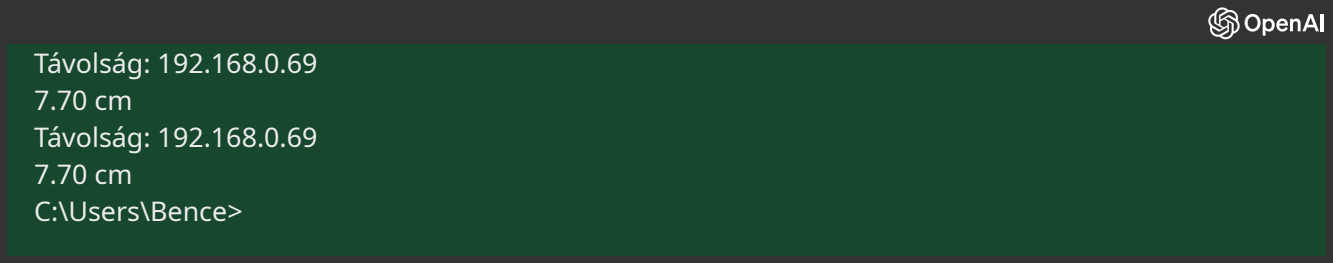
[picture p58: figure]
Távolság: 192.168.0.69 7.70 cm Távolság: 192.168.0.69 7.70 cm C:\Users\Bence>

Köszönöm a részletes infót — így látni, hogy az ESP8266 csatlakozik a WiFi-re, IP-t kap (192.168.0.69), soros porton működik a távolságmérés, de a weboldalt nem éred el, és a ping sem működik.
Ez alapján:

## 🚨 Mi lehet a gond? – Részletes hibakeresés

1. 🔥 A ping nem működik – ez normális ESP8266-nál

Az ESP8266 alapból nem válaszol ping-re (ICMP-re).
Ez nem jelenti azt, hogy a webserver nem működik.
Tehát ha `ping`-re nincs válasz, attól még elérhető lehet a weboldal. ✅ Próbáld elérni a böngészőből:

Menj a böngészőbe, és írd be:

cpp

http://192.168.0.69/

Ez vagy a helyi weboldalt jeleníti meg, vagy hibaüzenetet ad.

2. 📛 A tűzfal blokkolhatja (PC-n vagy routeren)
- Windows tűzfal

Ha a számítógéped privát helyett nyilvános hálózatként kezeli az otthoni WiFi-t, blokkolhatja a kérést.
Próbáld ideiglenesen kikapcsolni a Windows tűzfalat vagy engedélyezd a `ping` és a `HTTP` kapcsolatokat.
- Router izolációs beállítás

Néhány routerben van olyan beállítás, hogy kliensek elszigetelése:
Pl. “AP isolation” vagy “Client Isolation”.
Ha ez be van kapcsolva, a számítógéped nem tud kommunikálni a mikrokontrollerrel, csak a netre.
👉 Megoldás: Router admin felületén kapcsold ki a kliens izolációt, ha van ilyen opció.
Printed using ChatGPT to PDF, (https://pdfcrowd.com/chatgpt-to-pdf/?ref=chatgpt) powered by PDFCrowd HTML to PDF API. (https://pdfcrowd.com/api/html-to-pdf-api/?ref=chatgpt) | 10/24

3. 📲 Használj telefonos hotspotot (teszteléshez)

Ha nem vagy biztos a router beállításaiban, próbáld ki ezt:

Telefonodon hozz létre hotspotot:

SSID: `Bwifi`

Jelszó: `password`
Csatlakoztasd rá az ESP8266-ot.
Csatlakoztasd rá a laptopot is.

Próbáld elérni újra: `http://<az ESP8266 IP-je>/`

4. 📟 Ellenőrzés: valóban elindult a webserver?

Tedd ezt a soros porton a kódba:

cpp

Serial.println("Webszerver fut: http://" + WiFi.localIP().toString());

Ez segít látni, hogy valóban beindult a szerver.

5. 🧪 Extra ellenőrzés: használj `curl` vagy `telnet`-et

Parancssorból kipróbálhatod:

bash

curl http://192.168.0.69/

vagy

bash

telnet 192.168.0.69 80

Ha csatlakozik, akkor a szerver hallgat, csak valami más akadályozza a kapcsolatot (tűzfal, router izoláció stb.).

## ➕ Összefoglalva

Probléma | Megoldás
Nincs ping válasz | Normális, ESP8266 nem válaszol ICMP-re
Weboldal nem elérhető | Próbáld böngészőben, ne csak `ping`-gel
Tűzfal, router blokkol | Ellenőrizd a kliens izolációt és tűzfalat
Hotspot teszt | Gyorsan kizárja router hibát
Printed using ChatGPT to PDF, (https://pdfcrowd.com/chatgpt-to-pdf/?ref=chatgpt) powered by PDFCrowd HTML to PDF API. (https://pdfcrowd.com/api/html-to-pdf-api/?ref=chatgpt) | 11/24

Ha szeretnéd, elküldöm a pontos lépéseket tűzfal beállításra vagy router izoláció kikapcsolására. Melyik routered van?

A webhely nem érhető el
A(z) 192.168.0.69 túl hosszú ideje nem válaszol. Próbálja ki a következőket:

A kapcsolat ellenőrzése
A proxy és a tűzfal ellenőrzése
A Windows Hálózati diagnosztika futtatása
ERR_CONNECTION_TIMED_OUT

Köszi, most már egyértelmű a helyzet:
Az ESP8266 csatlakozik a WiFi-re, IP-címet kap, de a webszerver nem érhető el, és timeoutol.
Ez nem hálózati probléma elsődlegesen, hanem az ESP8266 oldalon valamiért nem fut a webserver, vagy nem figyel port 80-on.

## ✅ Gyorsteszt: egyszerű webszerver 1 oldallal

Futtasd le ezt az ultra-minimál kódot, ami csak a webszervert teszteli:

cpp

#include <ESP8266WiFi.h>

#include <ESP8266WebServer.h>

const char* ssid = "Bwifi"; const char* password = "password";

ESP8266WebServer webServer(80);

void handleRoot() {
webServer.send(200, "text/plain", "ESP8266 működik!"); }

void setup() {
Serial.begin(115200);
WiFi.begin(ssid, password);

Serial.print("Csatlakozás WiFi-hez"); while (WiFi.status() != WL_CONNECTED) { delay(500);
Serial.print(".");
}

Serial.println();
Serial.print("Csatlakozva! IP: "); Serial.println(WiFi.localIP());

webServer.on("/", handleRoot); webServer.begin();
Serial.println("Webszerver elindítva"); }

void loop() {
webServer.handleClient();
}
Printed using ChatGPT to PDF, (https://pdfcrowd.com/chatgpt-to-pdf/?ref=chatgpt) powered by PDFCrowd HTML to PDF API. (https://pdfcrowd.com/api/html-to-pdf-api/?ref=chatgpt) | 12/24

Ezután:

### 1. Soros monitoron látni fogod az IP-címet (pl. `192.168.0.69`) 2. Menj a böngészőbe és írd be:

cpp

http://192.168.0.69/

### 3. Ha minden jó, ezt fogod látni:

nginx

ESP8266 működik!

## 🔍 Ha ez SEM működik:

Akkor 99%, hogy a gond a következő lehet:
1. ⚠️ Túl sok soros port kiírás, túl gyakran

Az eredeti kódod 250 ms-onként ír soros portra + újratölt weblapot = ez túlterhelheti az ESP8266-ot.
2. ⚡ Tápellátás elégtelen

Az ultrahangos szenzor (HC-SR04) hirtelen áramigénye miatt instabillá válhat a mikrokontroller.

Ha USB-ről laptopra van kötve, és HC-SR04 is tápot onnan vesz, könnyen lehet alultáplálás. Megoldás:
Külső 5V táp a HC-SR04-nek (pl. USB powerbank + 5V–>3.3V átalakító)
vagy csak próbáld le a szenzort a kódból.
3. 🚫 Nincs `webServer.handleClient()` a `loop()`-ban

Ez is gyakori hiba — a webszerver csak akkor válaszol, ha ez a sor rendszeresen fut.

## 📌 Következő lépés

✅ Ha a fenti tesztkód működik, akkor a gond a távolságmérő kód vagy a frissítés túl sűrűsége. Ebben az esetben szívesen újraírom neked stabilabb, AJAX-alapú változatra.
Ha a tesztkód SEM működik, akkor hálózati szintű problémáról van szó (router, táp, firmware). Szeretnéd, hogy küldjek egy végleges verziót stabil webes frissítéssel is?
Printed using ChatGPT to PDF, (https://pdfcrowd.com/chatgpt-to-pdf/?ref=chatgpt) powered by PDFCrowd HTML to PDF API. (https://pdfcrowd.com/api/html-to-pdf-api/?ref=chatgpt) | 13/24

A `duration` pontosabbá tételéhez az alábbi dolgokat lehet tenni:

## ✅ 1. Használj `micros()` alapú mérést

A `pulseIn()` függvény egyszerű és jól működik, de nem a legpontosabb. Ha nagyon precíz mérést szeretnél, válts át `micros()` használatára manuálisan:

cpp

float measureDistance() {
digitalWrite(trigPin, LOW); delayMicroseconds(2);
digitalWrite(trigPin, HIGH); delayMicroseconds(10);
digitalWrite(trigPin, LOW);

// Precízebb időmérés
unsigned long startTime = micros();
while (digitalRead(echoPin) == LOW) {
if (micros() - startTime > 30000) return -1; // timeout }

unsigned long echoStart = micros();
while (digitalRead(echoPin) == HIGH) {
if (micros() - echoStart > 30000) return -1; // timeout }
unsigned long echoEnd = micros();

unsigned long duration = echoEnd - echoStart;
float distance = duration * 0.0343 / 2.0; // cm return distance;
}

Ez pontosabb, mert a `pulseIn()` néha torzít hosszabb vagy túl gyors impulzusoknál. A fenti módszer:

manuálisan figyeli a pin állapotát,
mikroszekundum pontossággal számol,
leáll timeouttal, ha nincs visszaverődő jel.

## ✅ 2. Hardveres pontosság javítása

Ha a szenzor hibázik, az nem mindig a kód hibája. Ezeket is ellenőrizd:

Tiszta 5V táp (ne csak az ESP8266 USB-jéről!)
Közvetlen, rövid vezetékek a HC-SR04-hez
Kerüld a zajos környezetet vagy visszaverődéseket (túl közeli tárgy, textil, tükröződés)

## ✅ 3. Átlagolás: többszöri mérés simítása

Ha stabil értéket szeretnél (pl. 3 mérést átlagolni):

Printed using ChatGPT to PDF, (https://pdfcrowd.com/chatgpt-to-pdf/?ref=chatgpt) powered by PDFCrowd HTML to PDF API. (https://pdfcrowd.com/api/html-to-pdf-api/?ref=chatgpt) | 14/24

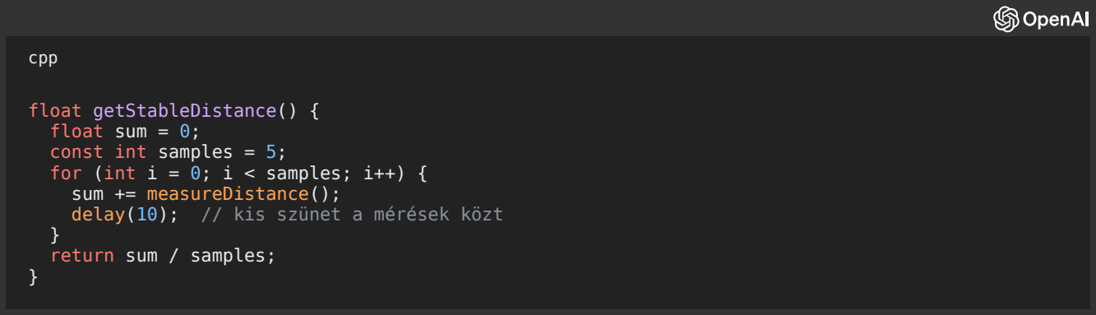
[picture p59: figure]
cpp; float getStableDistance() { float sum = 0; const int samples = 5; for (int i = 0; i < samples; i++) { sum += measureDistance(); delay(10); // kis szünet a mérések közt; } return sum / samples;

## 💡 Végül

A HC-SR04 szenzor elméleti felbontása: kb. 0.3 cm, de a valóságban 1–2 cm pontosság a jellemző. A fenti trükkökkel kihozható belőle a legjobb.
Ha szeretnéd, írok teljes, AJAX-os webes verziót pontos méréssel és átlagolással együtt. Csak szólj!

írj egy html css normálisan kinéző weblapot ahol a raw értéket is kiirja sötét desinggel

Rendben! Itt van egy letisztult, sötét témájú, modern HTML+CSS weblap, amely az ESP8266-ról érkező távolság (cm) és nyers `duration` értéket jeleníti meg.
A tartalom AJAX-szal frissül 250 ms-onként.

🧩 HTML + CSS + JavaScript (AJAX) – sötét dizájn

cpp

const char MAIN_page[] PROGMEM = R"=====(

<!DOCTYPE html>
<html lang="hu">
<head>
<meta charset="UTF-8">
<title>Távolságmérő</title>
<meta name="viewport" content="width=device-width, initial-scale=1"> <style>
body {
background-color: #121212;
color: #e0e0e0;
font-family: 'Segoe UI', sans-serif; text-align: center;
padding: 2rem;
}

h1 {
color: #bb86fc;
}

.box {
background: #1e1e1e;
border-radius: 12px;
padding: 1.5rem;
margin: 1rem auto;
width: 90%;
max-width: 400px;
box-shadow: 0 0 15px rgba(0,0,0,0.3);
Printed using ChatGPT to PDF, (https://pdfcrowd.com/chatgpt-to-pdf/?ref=chatgpt) powered by PDFCrowd HTML to PDF API. (https://pdfcrowd.com/api/html-to-pdf-api/?ref=chatgpt) | 15/24

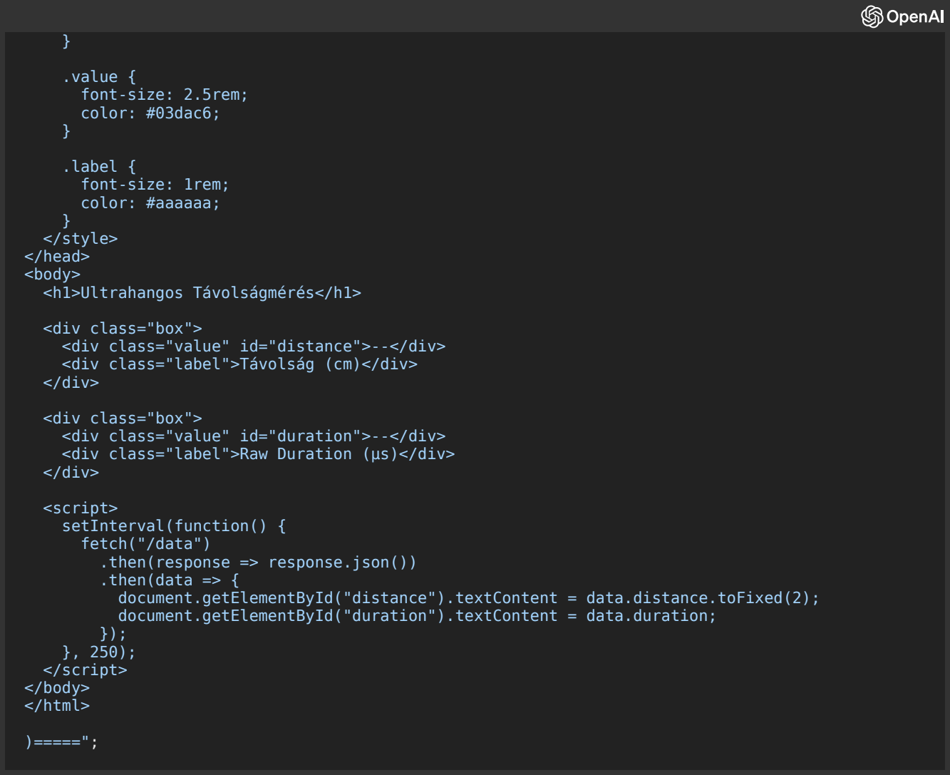
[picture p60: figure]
.value { font-size: 2.5rem; color: #03dac6;; .label { font-size: 1rem; color: #aaaaaa;; } </style> </head> <body> <h1>Ultrahangos Távolságmérés</h1>; <div class="box"> <div class="value" id="distance">--</div> <div class="label">Távolság (cm)</div> </div>; <div class="box"> <div class="value" id="duration">--</div> <div class="label">Raw Duration (µs)</div> </div>; <script> setInterval(function() { fetch("/data") .then(response => response.json()) .then(data => { document.getElementById("distance").textContent = data.distance.toFixed(2)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

🔧 Backend (ESP8266 oldali kiszolgálás)

A `/data` endpoint JSON-t ad vissza:

cpp

void handleData() {
long duration = pulseIn(echoPin, HIGH);
float distance = duration * 0.0343 / 2.0;

String json = "{\"duration\": " + String(duration) + ", \"distance\": " + String(distance, 2) + "} server.send(200, "application/json", json);
}

🧩 Fontos: a szerver beállítása

cpp

#include <ESP8266WiFi.h>

#include <ESP8266WebServer.h>

const char* ssid = "Bwifi";
const char* password = "password";

const int trigPin = D1;
Printed using ChatGPT to PDF, (https://pdfcrowd.com/chatgpt-to-pdf/?ref=chatgpt) powered by PDFCrowd HTML to PDF API. (https://pdfcrowd.com/api/html-to-pdf-api/?ref=chatgpt) | 16/24

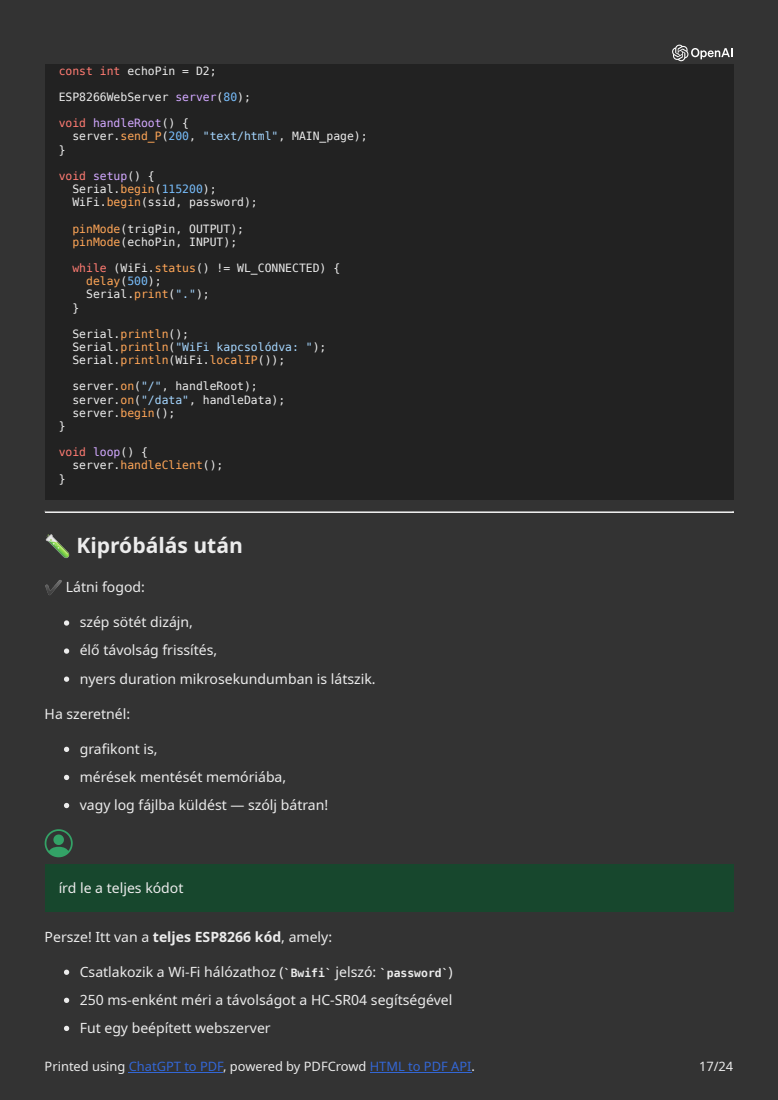
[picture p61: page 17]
ESP8266WebServer server(80);; void loop() { server.handleClient();; 🧪 Kipróbálás után; Printed using ChatGPT to PDF, powered by PDFCrowd HTML to PDF API.

const int echoPin = D2;

void handleRoot() {
server.send_P(200, "text/html", MAIN_page);

void setup() {
Serial.begin(115200);
WiFi.begin(ssid, password);

pinMode(trigPin, OUTPUT);
pinMode(echoPin, INPUT);

while (WiFi.status() != WL_CONNECTED) {
delay(500);
Serial.print(".");

Serial.println();
Serial.println("WiFi kapcsolódva: ");
Serial.println(WiFi.localIP());

server.on("/", handleRoot);
server.on("/data", handleData);
server.begin();

✔️ Látni fogod:
szép sötét dizájn,
élő távolság frissítés,
nyers duration mikrosekundumban is látszik.
Ha szeretnél:
grafikont is,
mérések mentését memóriába,
vagy log fájlba küldést — szólj bátran!

írd le a teljes kódot

Persze! Itt van a teljes ESP8266 kód, amely:
Csatlakozik a Wi-Fi hálózathoz (`Bwifi` jelszó: `password`)
250 ms-enként méri a távolságot a HC-SR04 segítségével
Fut egy beépített webszerver

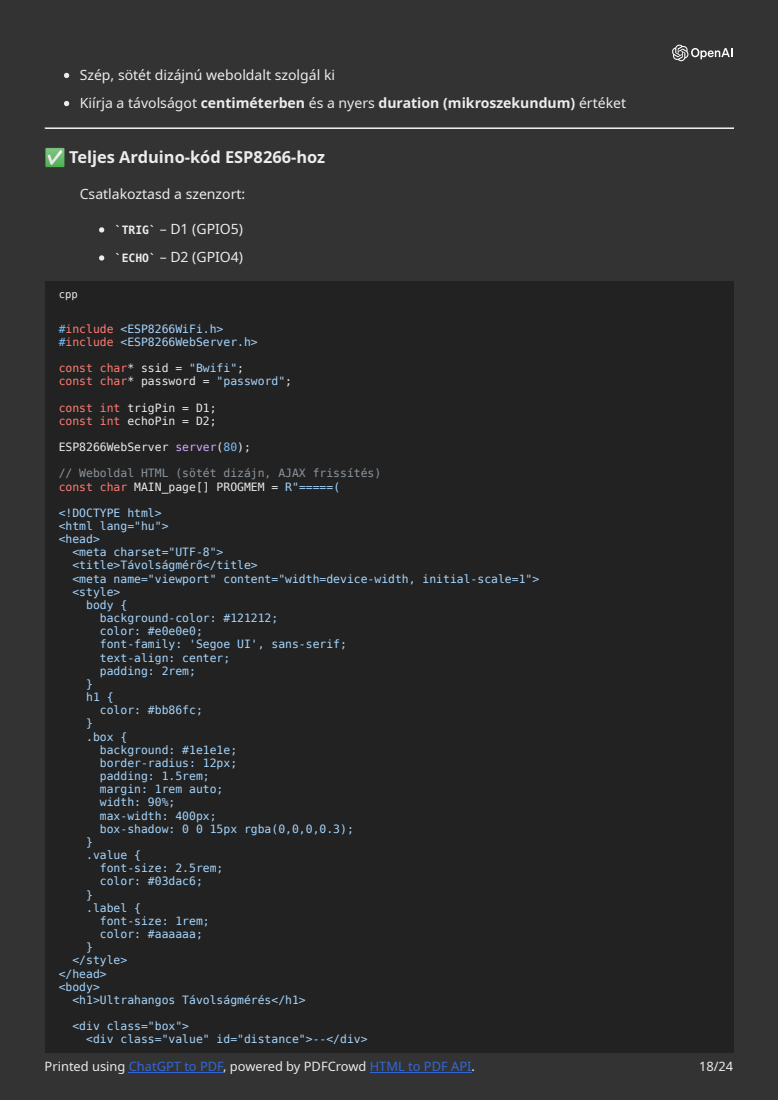
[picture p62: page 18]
Csatlakoztasd a szenzort:; `TRIG` – D1 (GPIO5) `ECHO` – D2 (GPIO4); cpp; #include <ESP8266WiFi.h> #include <ESP8266WebServer.h>; ESP8266WebServer server(80);; Printed using ChatGPT to PDF, powered by PDFCrowd HTML to PDF API.

Szép, sötét dizájnú weboldalt szolgál ki
Kiírja a távolságot centiméterben és a nyers duration (mikroszekundum) értéket

✅ Teljes Arduino-kód ESP8266-hoz

const char* ssid = "Bwifi";
const char* password = "password";

const int trigPin = D1;
const int echoPin = D2;

// Weboldal HTML (sötét dizájn, AJAX frissítés)
const char MAIN_page[] PROGMEM = R"=====(

<!DOCTYPE html>
<html lang="hu">
<head>
<meta charset="UTF-8">
<title>Távolságmérő</title>
<meta name="viewport" content="width=device-width, initial-scale=1">
<style>
body {
background-color: #121212;
color: #e0e0e0;
font-family: 'Segoe UI', sans-serif;
text-align: center;
padding: 2rem;
color: #bb86fc;
.box {
background: #1e1e1e;
border-radius: 12px;
padding: 1.5rem;
margin: 1rem auto;
width: 90%;
max-width: 400px;
box-shadow: 0 0 15px rgba(0,0,0,0.3);
.value {
font-size: 2.5rem;
color: #03dac6;
.label {
font-size: 1rem;
color: #aaaaaa;
</style>
</head>
<body>
<h1>Ultrahangos Távolságmérés</h1>

<div class="box">
<div class="value" id="distance">--</div>

<div class="label">Távolság (cm)</div> </div>

<div class="box">
<div class="value" id="duration">--</div> <div class="label">Raw Duration (µs)</div> </div>

<script>
setInterval(function() {
fetch("/data")
.then(response => response.json())
.then(data => {
document.getElementById("distance").textContent = data.distance.toFixed(2); document.getElementById("duration").textContent = data.duration;
});
}, 250);
</script>
</body>
</html>

)=====";

// Mérési függvény
float distanceCM = 0.0;
long duration = 0;

void measureDistance() {
digitalWrite(trigPin, LOW); delayMicroseconds(2);
digitalWrite(trigPin, HIGH);
delayMicroseconds(10);
digitalWrite(trigPin, LOW);

duration = pulseIn(echoPin, HIGH, 30000); // max 30ms = ~5m distanceCM = duration * 0.0343 / 2.0;
}

// Weboldal és adatválaszok
void handleRoot() {
server.send_P(200, "text/html", MAIN_page); }

void handleData() {
measureDistance();
String json = "{\"duration\": " + String(duration) + ", \"distance\": " + String(distanceCM, 2) + server.send(200, "application/json", json);
}

// Alap setup
void setup() {
Serial.begin(115200);
pinMode(trigPin, OUTPUT);
pinMode(echoPin, INPUT);

WiFi.begin(ssid, password); Serial.print("Csatlakozás WiFi-hez"); while (WiFi.status() != WL_CONNECTED) { delay(500);
Serial.print(".");
}

Serial.println();
Serial.print("Csatlakozva! IP-cím: "); Serial.println(WiFi.localIP());

server.on("/", handleRoot); server.on("/data", handleData); server.begin();
Serial.println("Webszerver elindult."); }

void loop() {

Printed using ChatGPT to PDF, (https://pdfcrowd.com/chatgpt-to-pdf/?ref=chatgpt) powered by PDFCrowd HTML to PDF API. (https://pdfcrowd.com/api/html-to-pdf-api/?ref=chatgpt) | 19/24

🔌 Fontos tanácsok

Az ESP8266 nem válaszol `ping`-re – a weboldalt közvetlen IP-vel érd el:
→ `http://192.168.0.xx/` (ahol az IP-t a soros monitoron látod)
A `pulseIn(..., timeout)` használat védi a mikrokontrollert lefagyástól
Ha instabil, győződj meg róla, hogy a HC-SR04 megfelelő 5V tápot kap, és esetleg tegyél 1k/2k osztót az `ECHO`-ra

Ha szeretnél grafikont vagy extra funkciókat (pl. max / min távolság naplózása), szívesen segítek!

JEDLIKBOTS

Jedlik Ányos Technikum Robotika Csapata
log
Innovatív robotika a Jedlikből
Üdvözlünk a JedlikBots oldalán! Mi vagyunk a Győri Jedlik Ányos Technikum lelkes szoftverfejlesztő diákcsapata, akik a robotika világában alkotnak. Csapatunk szenvedélyesen dolgozik innovatív robotikai megoldásokon, és büszkén mutatjuk be az elmúlt évek során elért eredményeinket.

Célunk, hogy ne csak megvalósítsuk elképzeléseinket, hanem folyamatosan fejlesszük készségeinket és tudásunkat, miközben gyakorlati tapasztalatot szerzünk a szoftverfejlesztés, a mechanikai tervezés és az elektronika területén.

Jelenleg egy professzionális versenyzésre és komplex technológiai demonstrációkra is alkalmas új robot fejlesztésén dolgozunk, és keressük azokat a támogatókat, akik hisznek a fiatal technológiai tehetségekben és segítenének álmaink megvalósításában!

Csapattagok
Nagy Bence
Nagy Bence
Szoftverfejlesztő

Szakterület: szenzoradatok feldolgozása, robotvizualizáció

Bence feladata a robotok érzékelőinek adatgyűjtése és valós idejű feldolgozása. Kiváló 3D-modellező, robotjaink vizuális megjelenítésén és szimulációs környezetének fejlesztésén dolgozik.

Nagy Bence
Szitás László
Szoftverfejlesztő

Szakterület: felhasználói felületek, projektmenedzsment

Printed using ChatGPT to PDF, (https://pdfcrowd.com/chatgpt-to-pdf/?ref=chatgpt) powered by PDFCrowd HTML to PDF API. (https://pdfcrowd.com/api/html-to-pdf-api/?ref=chatgpt) | 20/24

László fejleszti a robotjaink vezérlő felületeit és webes alkalmazásait. Innovatív megoldásaival biztosítja, hogy bárki könnyen kommunikálhasson és vezérelhesse robotjainkat. Emellett ő tartja kézben a projektek ütemezését és koordinálását.

Nagy Bence
Schmidt Nándor
Szoftverfejlesztő

Szakterület: beágyazott rendszerek, elektronikai tervezés

Nándor a robotok "agya" mögött álló beágyazott rendszerek szakértője. Az alacsony szintű programozás és firmware fejlesztés mestere, aki biztosítja, hogy robotjaink gyorsan és hatékonyan reagáljanak.

Buda Bálint
Buda Bálint
Szoftverfejlesztő

Szakterület: robotvezérlés, Gépi látás

Bálint felelős a robotok vezetékes és vezeték nélküli kommunikációjáért, valamint a gépi tanulási algoritmusok implementálásáért, amelyek segítenek robotjainknak alkalmazkodni a változó környezeti feltételekhez.

Projektjeink
WRO 2025 regionális döntő Budapest
Üdvözlünk a JedlikBots oldalán! Mi vagyunk a Győri Jedlik Ányos Technikum lelkes szoftverfejlesztő diákcsapata, akik a robotika világában alkotnak. Csapatunk szenvedélyesen dolgozik innovatív robotikai megoldásokon, hogy versenyeken érhessünk el sikereket.

A Budapesti WRO (World Robot Olympiad) regionális döntőjéig jutottunk el EV3-as Mindstorms robotunkkal, ahol sikeresen 2. helyezést értünk el, ezzel kvalifikálva magunkat a nemzeti döntőre. Jelenleg erre a kihívásra készülünk, de már a jövő évi céljainkat is kitűztük.

Jövőre ugyanezen a versenyen szeretnénk elérni a világdöntőre való kijutást, hogy képviselhessük Magyarországot a nemzetközi mezőnyben. A lenti videón látható jelenlegi robotunk és a használt technológia sajnos nem elegendő ahhoz, hogy reális esélyünk legyen a világdöntőn való eredményes szereplésre, ezért szeretnénk egy fejlettebb robotot építeni a következő évi megmérettetésre.

Jelenleg támogatókat keresünk, akik hisznek a fiatal technológiai tehetségekben és segítenének álmaink megvalósításában. A jelenlegi robotunk bemutatóját az alábbi videón tekintheted meg!

Jelenlegi projektünk: ProBot X1
A ProBot X1 egy multifunkcionális, moduláris robot platformunk, amellyel nemzetközi versenyeken szeretnénk részt venni. A robot jelenlegi fejlesztési szakaszában vagyunk, és olyan támogatókat keresünk, akik a fejlesztéshez szükséges alkatrészekkel, eszközökkel tudnák segíteni a munkánkat.

Fejlesztési előrehaladás:
Printed using ChatGPT to PDF, (https://pdfcrowd.com/chatgpt-to-pdf/?ref=chatgpt) powered by PDFCrowd HTML to PDF API. (https://pdfcrowd.com/api/html-to-pdf-api/?ref=chatgpt) | 21/24

10%
Műszaki tervek:
Beépített mélységérzékelő kamerák a térbeli tájékozódáshoz Fejlett gépi tanulási algoritmusok az objektumfelismeréshez Moduláris kialakítás, könnyen cserélhető alkatrészekkel Akkumulátor üzemidő: 2+ óra aktív használat mellett
Több irányba fordítható kamera, gépi látással feldolgozva adatait Professzionális robot, bármilyen feladatra
Eszközigény – támogatással segíthető alkatrészek:
Raspberry Pi bármely változata (akár Compute Module is) Léptetőmotorok, motorvezérlők, kisebb villanymotorok
Szenzorok: színérzékelő, gyorsulásmérő, giroszkóp, kameramodulok Próbapanelek, jumperkábelek, USB–TTL konverterek
STM-alapú mikrokontroller panelek
3D nyomtató filament (1.75 mm)
Érintőkijelzők (akár hibás, ha javítható)
Logikai analizátor a hibakereséshez
RGB LED-ek állapotjelzéshez
Bármilyen támogatás – akár egyetlen eszközzel – nagy segítséget jelent számunkra a projekt sikeres befejezéséhez és a versenyeken való részvételhez.

Eddigi eredményeink
2022. március
Robotprogramozó Országos Csapatverseny - 2. helyezés
Az Országos Robotprogramozó csapatversenyen a csapatunk 2. helyezést ért el. Ez volt az első országos versenyünk, amely bebizonyította, hogy csapatunk képes versenyképes robotokat építeni.

2023. március
Robotprogramozó Országos Csapatverseny - 1. helyezés
Ismét részt vettünk az Országos Robotprogramozó csapatversenyen, ahol ebben az évben a csapatunk már 1. helyezést ért el. Bebizonyítottuk, hogy képesek vagyunk az országos csúcsra törni.

2025. május
WRO 2025 Regionális Döntő Budapest - 2. helyezés
Az első WRO versenyünk, ahol a budapesti regionális döntőben 2. helyezést értünk el. Így bejutottunk a WRO országos döntőjébe. Jövőre ugyanezen a versenyen az új professzionális robottal a világdöntő a cél.

Támogasd a jövő mérnökeit!
Segítsd csapatunkat, hogy megvalósíthassuk álmainkat és innovatív projektjeinket!

Anyagi támogatás
Projektjeink megvalósításához folyamatosan eszközökre, alkatrészekre és anyagokra van szükségünk. Az anyagi támogatással közelebb kerülünk céljainkhoz.

Mire költjük: Elektronikai komponensek, mikrokontrollerek, mechanikai alkatrészek, szerszámok

Eszköz adományozás
Ha rendelkezel olyan használaton kívüli eszközökkel, amelyek segíthetik a munkánkat – például mikrokontrollerek, szenzorok, motorok –, hálásan fogadjuk!
Printed using ChatGPT to PDF, (https://pdfcrowd.com/chatgpt-to-pdf/?ref=chatgpt) powered by PDFCrowd HTML to PDF API. (https://pdfcrowd.com/api/html-to-pdf-api/?ref=chatgpt) | 22/24

Mentorálással, tanácsadással, vagy akár csak ötletekkel is sokat segíthetsz nekünk. Szívesen együttműködünk tapasztalt szakemberekkel, fejlesztőkkel. irj descripciont githubra ezek alapján

Íme egy profi, figyelemfelkeltő GitHub repository description magyar és angol nyelven, a megadott szöveg alapján – tökéletesen illik egy nyílt forráskódú vagy bemutató projekthez, például a ProBot X1-hez vagy a JedlikBots csapat arculatához:

## Magyar – README leírás / GitHub description

JedlikBots – A jövő robotikai mérnökei Győrből
Üdvözlünk a JedlikBots GitHub oldalán! 🎓🤖
Mi vagyunk a Győri Jedlik Ányos Technikum szoftverfejlesztő és robotika iránt elkötelezett csapata. Célunk, hogy innovatív, valós problémákra épülő robotikai megoldásokat hozzunk létre, miközben folyamatosan bővítjük tudásunkat a szoftverfejlesztés, elektronika és gépészet területén.
📌 Fő projekt: ProBot X1

Egy professzionális, moduláris robotplatform, mellyel a nemzetközi WRO versenyekre készülünk. A robot fejlett gépi látással, tanuló algoritmusokkal és cserélhető moduláris alkatrészekkel rendelkezik.
🎯 Küldetésünk

Versenyrobotok tervezése és fejlesztése (WRO, országos megmérettetések)
Szoftveres és beágyazott rendszerek integrálása
Oktatási célú nyílt forrású projektek bemutatása
Támogatók és mentorok bevonása a magyar műszaki utánpótlás erősítéséért
🔧 Eszközigény & támogatás

Támogass minket eszközzel vagy szakmai tanáccsal, hogy elérhessük a világdöntőt és inspiráljuk a jövő mérnökeit! Részletekért görgess lejjebb a README-ben vagy látogasd meg weboldalunkat.

## English – GitHub Repository Description

JedlikBots – Young Engineers from Hungary Building the Future of Robotics
Welcome to the official GitHub page of JedlikBots, a high school robotics team from Győr, Hungary . We are passionate software developers and hardware tinkerers working on competitive and educational robotics projects.
️ Main Project: ProBot X1

A modular, AI-powered robot platform designed for international robotics competitions such as the WRO. Features include 3D vision, smart object recognition, and swappable hardware components.
🎓 Our Mission
Printed using ChatGPT to PDF, (https://pdfcrowd.com/chatgpt-to-pdf/?ref=chatgpt) powered by PDFCrowd HTML to PDF API. (https://pdfcrowd.com/api/html-to-pdf-api/?ref=chatgpt) | 23/24

Build competitive and educational robots from scratch Master embedded systems and real-time data processing Share open-source solutions and promote youth engineering Seek sponsors and mentors to help us grow professionally
🤝 How You Can Help

We're looking for supporters, mentors, and hardware donations (sensors, microcontrollers, motors, etc.) to bring our robots to life and represent Hungary on the world stage. More info in the full README.

Ha szeretnéd, csinálhatok egy látványos `README.md`-et is GitHubra képekkel, badge-ekkel, technológiákkal. Mondhatod, mi legyen benne még!

A Wemos D1 Mini-től és az ESP8266-tól függően a PlatformIO-ban használt board neve a következő: ✅ PlatformIO board neve Wemos D1 Mini-hez (ESP8266):

ini

board = d1_mini

️ Teljes `platformio.ini` példa:

ini

[env:d1_mini]
platform = espressif8266
board = d1_mini
framework = arduino
monitor_speed = 115200
upload_speed = 921600

Ha ESP32-es lenne, akkor például `board = esp32dev` lenne, de mivel jelezted, hogy ESP8266 van, ez a megfelelő.

Ha szeretnéd, le is generálok neked egy teljes PlatformIO-projektet induláshoz (pl. `main.cpp` + `platformio.ini` + könyvtárak listája). Szólj!

Printed using ChatGPT to PDF, (https://pdfcrowd.com/chatgpt-to-pdf/?ref=chatgpt) powered by PDFCrowd HTML to PDF API. (https://pdfcrowd.com/api/html-to-pdf-api/?ref=chatgpt) | 24/24

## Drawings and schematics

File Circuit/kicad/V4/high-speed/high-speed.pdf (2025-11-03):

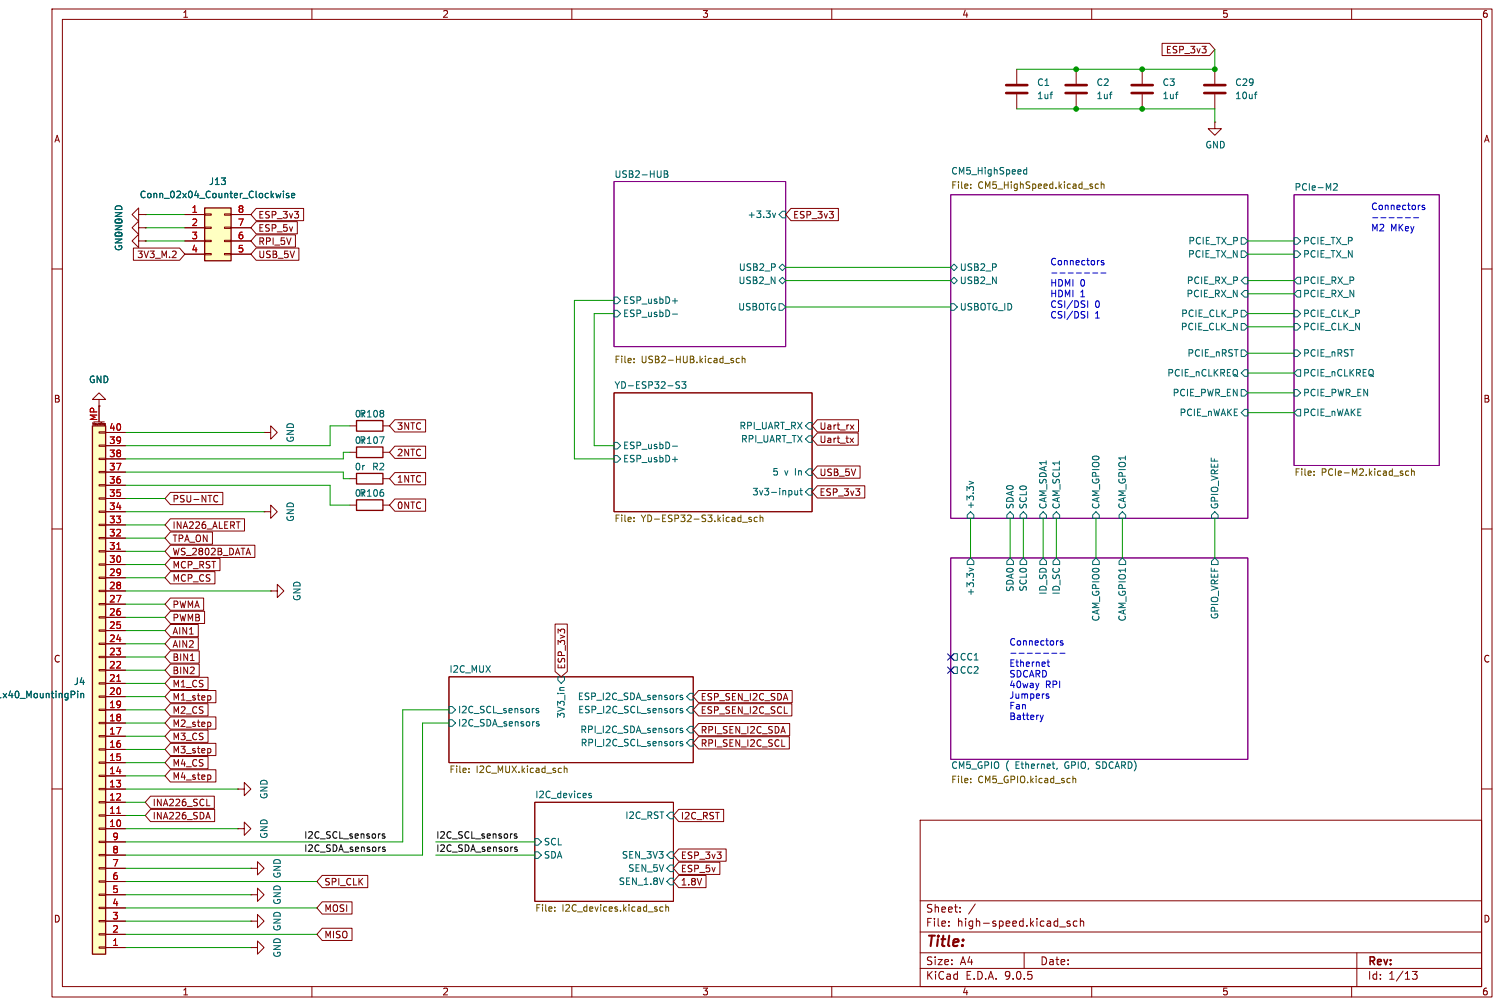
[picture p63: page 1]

GND
40way RPI Jumpers Fan Battery Connectors

Id: 1/13 Title: File: high-speed.kicad_sch Sheet: /

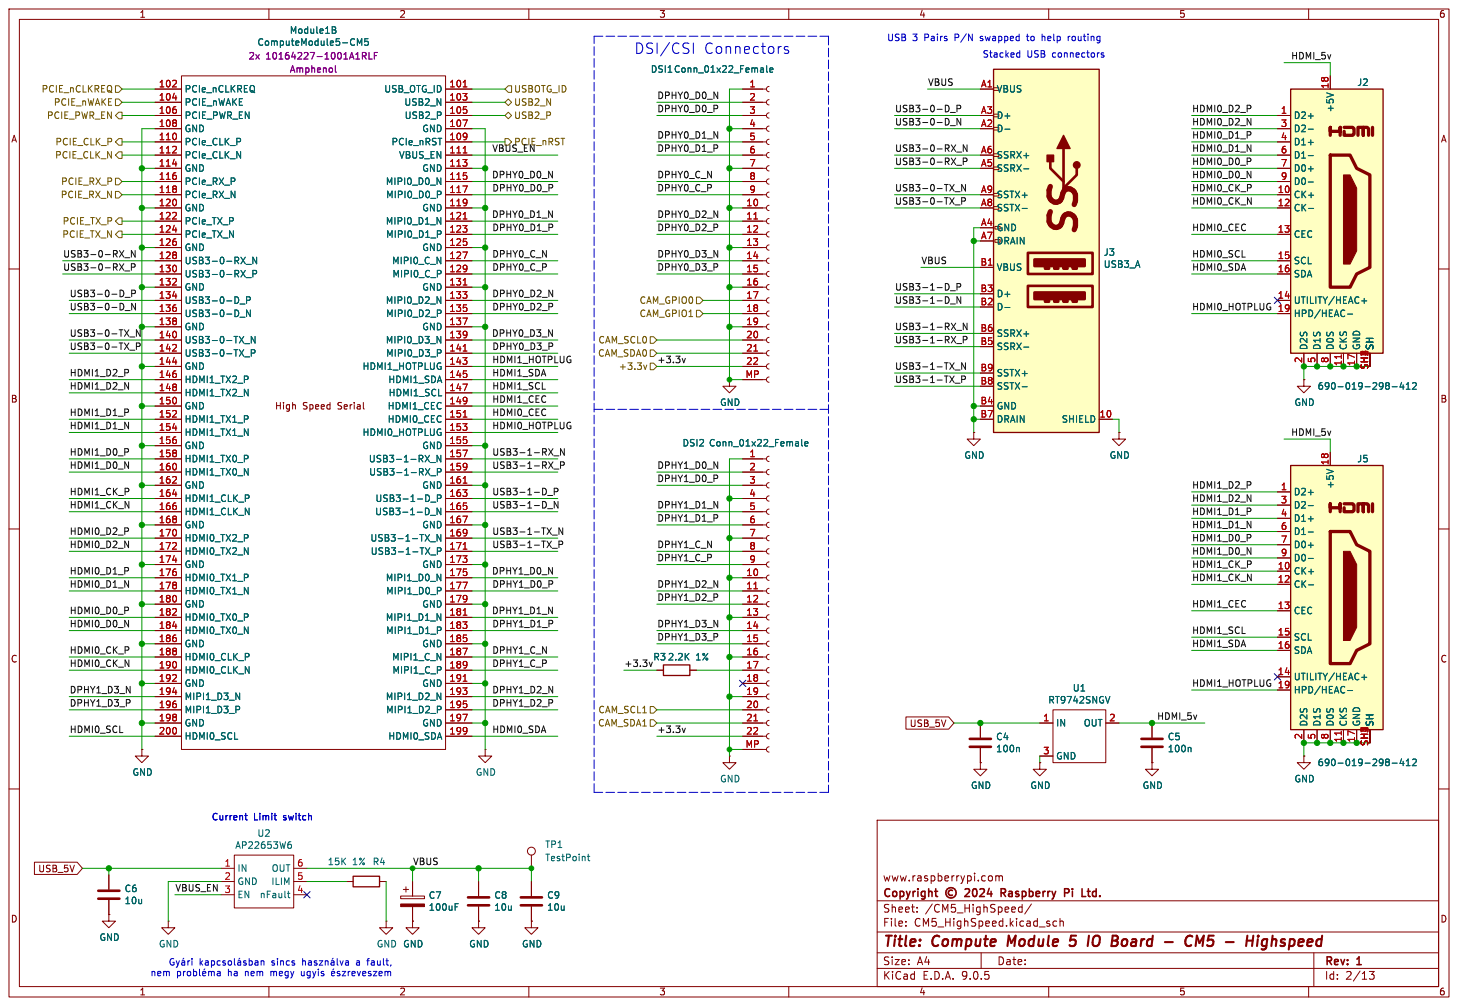
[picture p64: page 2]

USB 3 Pairs P/N swapped to help routing Stacked USB connectors Module1B ComputeModule5-CM5

DSI/CSI Connectors
22MP DSI1 Conn_01x22_Female
690-019-298-412 SH SH234 D2+ 1 D2- 3 D1+ 4 D1- 6 D0+ 7 D0- 9 CK+ 10 CK- 12 CEC 13 SCL 15 SDA 16 UTILITY/HEAC+ 14 HPD/HEAC- 19 D2S
HDMI0_SDA HDMI0_SCL HDMI0_D1_N
HDMI0_D0_P HDMI0_D0_N

8 CKS 11 GND 17 SH SH1

TP1 TestPoint GND GND GND

File: CM5_HighSpeed.kicad_sch Sheet: /CM5_HighSpeed/
Id: 2/13 Title: Compute Module 5 IO Board - CM5 - Highspeed

þÿGyári þÿkapcsolásban sincs þÿhasználva a fault, nem þÿprobléma ha nem megy ugyis þÿészreveszem

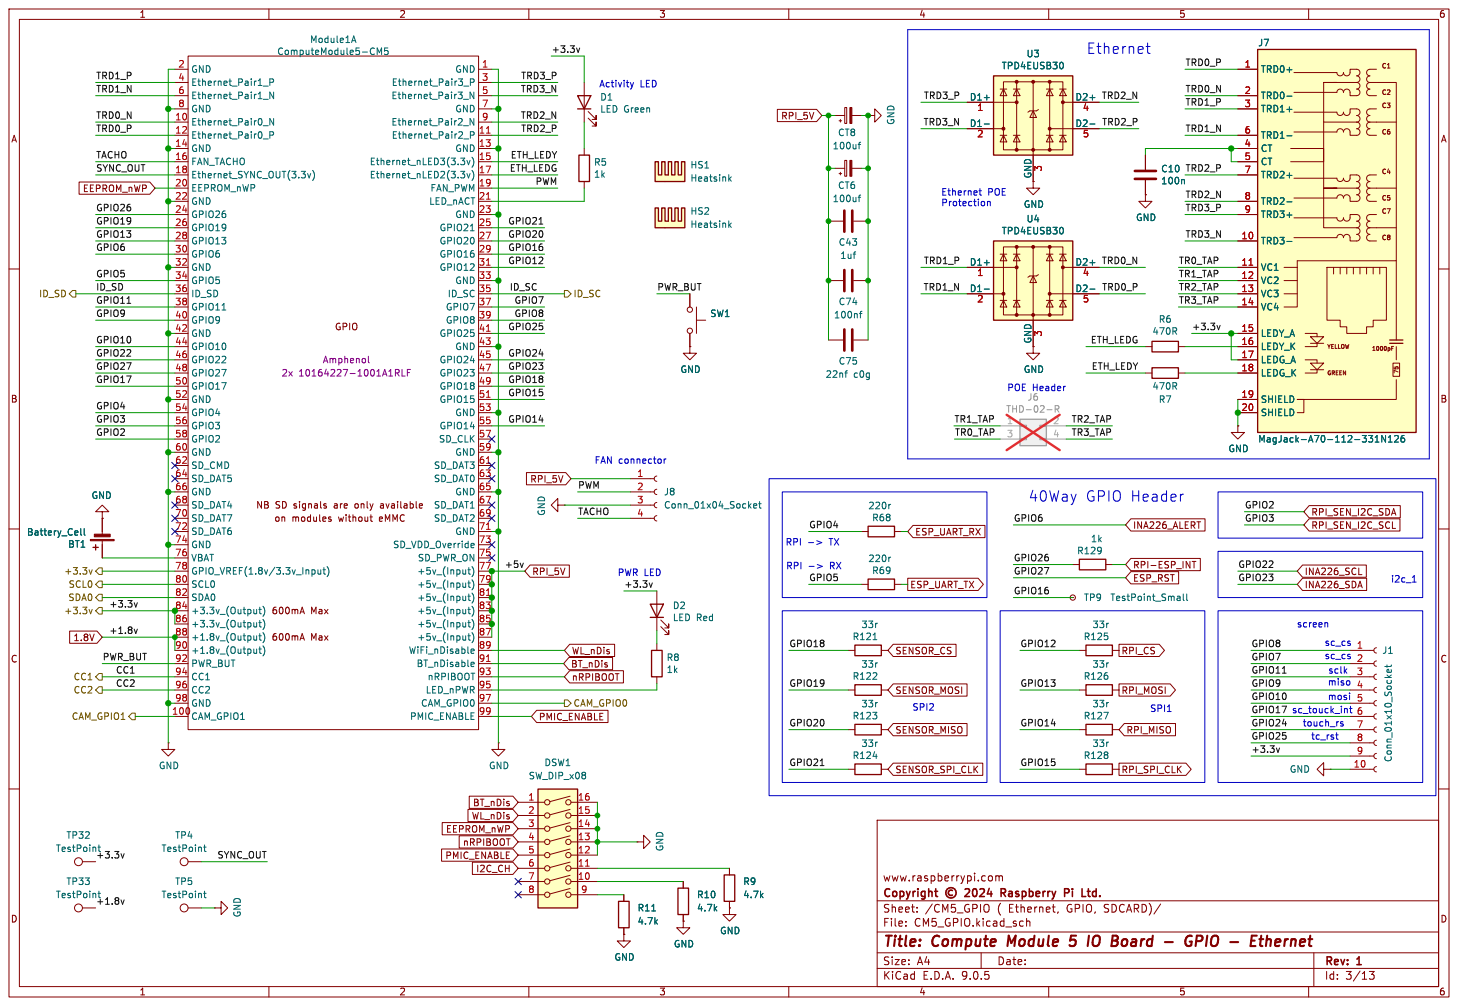
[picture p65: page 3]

sclk miso Ethernet GND

TP5 TestPoint TP4 TestPoint TP33 TestPoint TP32 TestPoint +3.3v

on modules without eMMC GPIO

600mA Max 600mA Max NB SD signals are only available

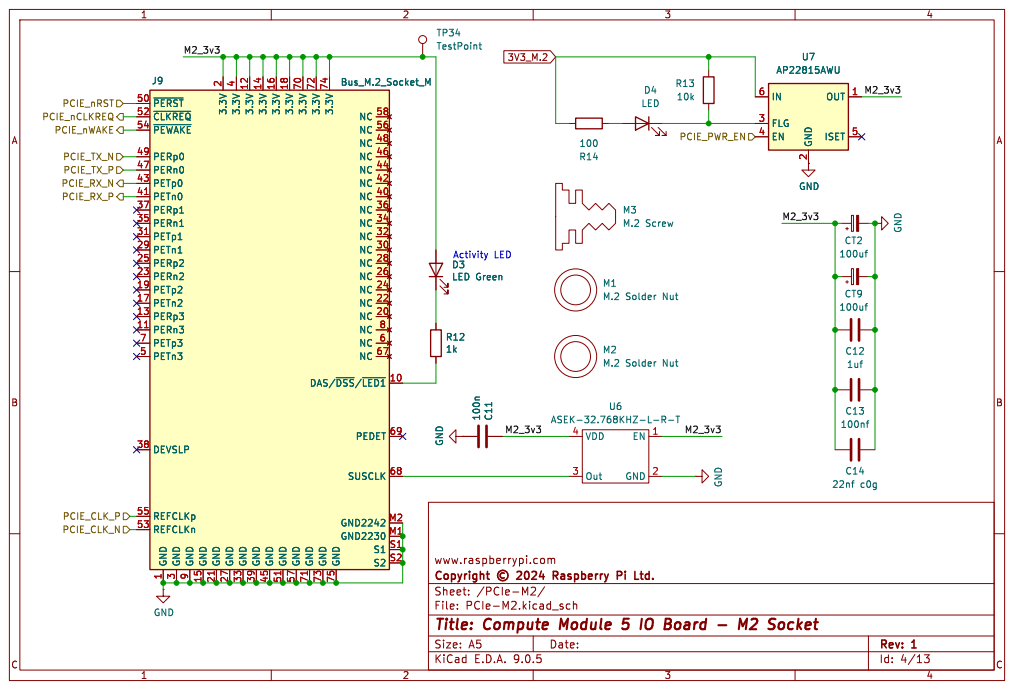
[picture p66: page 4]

4 GND 33 3.3V 12 GND 39 3.3V 14 GND 45 3.3V 16 GND 51 3.3V 18 GND 57 3.3V 70 GND 71 3.3V 72 GND 73 3.3V 74 GND 75 NC 58 NC 56 NC 48 NC 46 NC 44 NC 42 NC 40 NC 36 NC 34 NC 32 NC 30 NC 28 NC 26 NC 24 NC 22 NC 20 NC 8 NC 6 NC 67 DAS/~{DSS}/~{LED1} 10 PEDET 69 SUSCLK 68 GND2242 M2 GND2230 M1 S1 S1 S2 S2

4 GND 33 3.3V 12 GND 39 3.3V 14 GND 45 3.3V 16 GND 51 3.3V 18 GND 57 3.3V 70 GND 71 3.3V 72 GND 73 3.3V 74 GND 75 NC 58 NC 56 NC 48 NC 46 NC 44 NC 42 NC 40 NC 36 NC 34 NC 32 NC 30 NC 28 NC 26 NC 24 NC 22 NC 20 NC 8 NC 6 NC 67 DAS/~{DSS}/~{LED1} 10 PEDET 69 SUSCLK 68 GND2242 M2 GND2230 M1 S1 S1 S2 S2 100n C11 GND

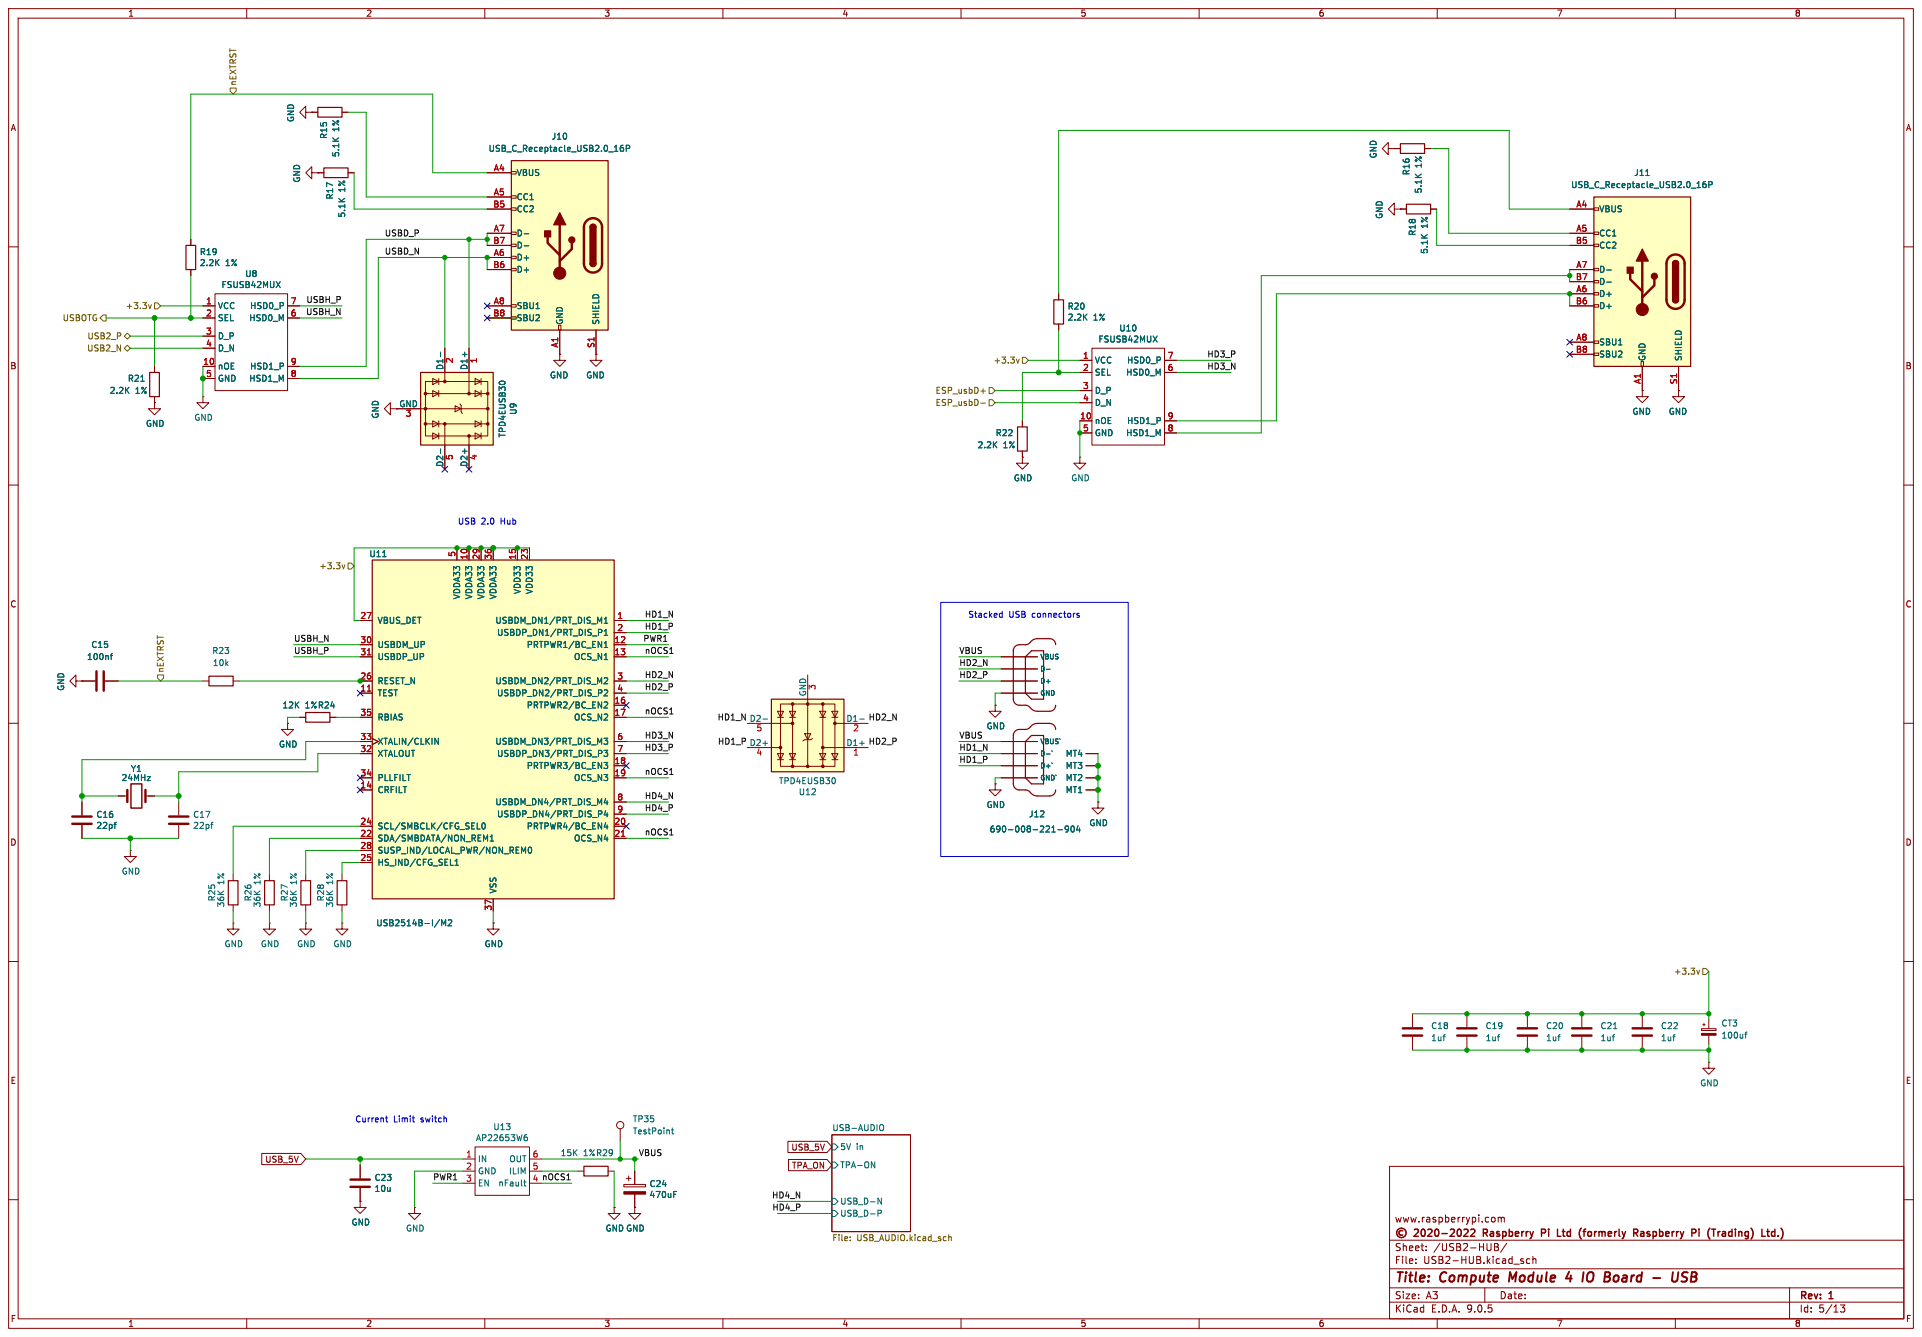
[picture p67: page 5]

Stacked USB connectors USB 2.0 Hub Current Limit switch

Id: 5/13 Title: Compute Module 4 IO Board - USB

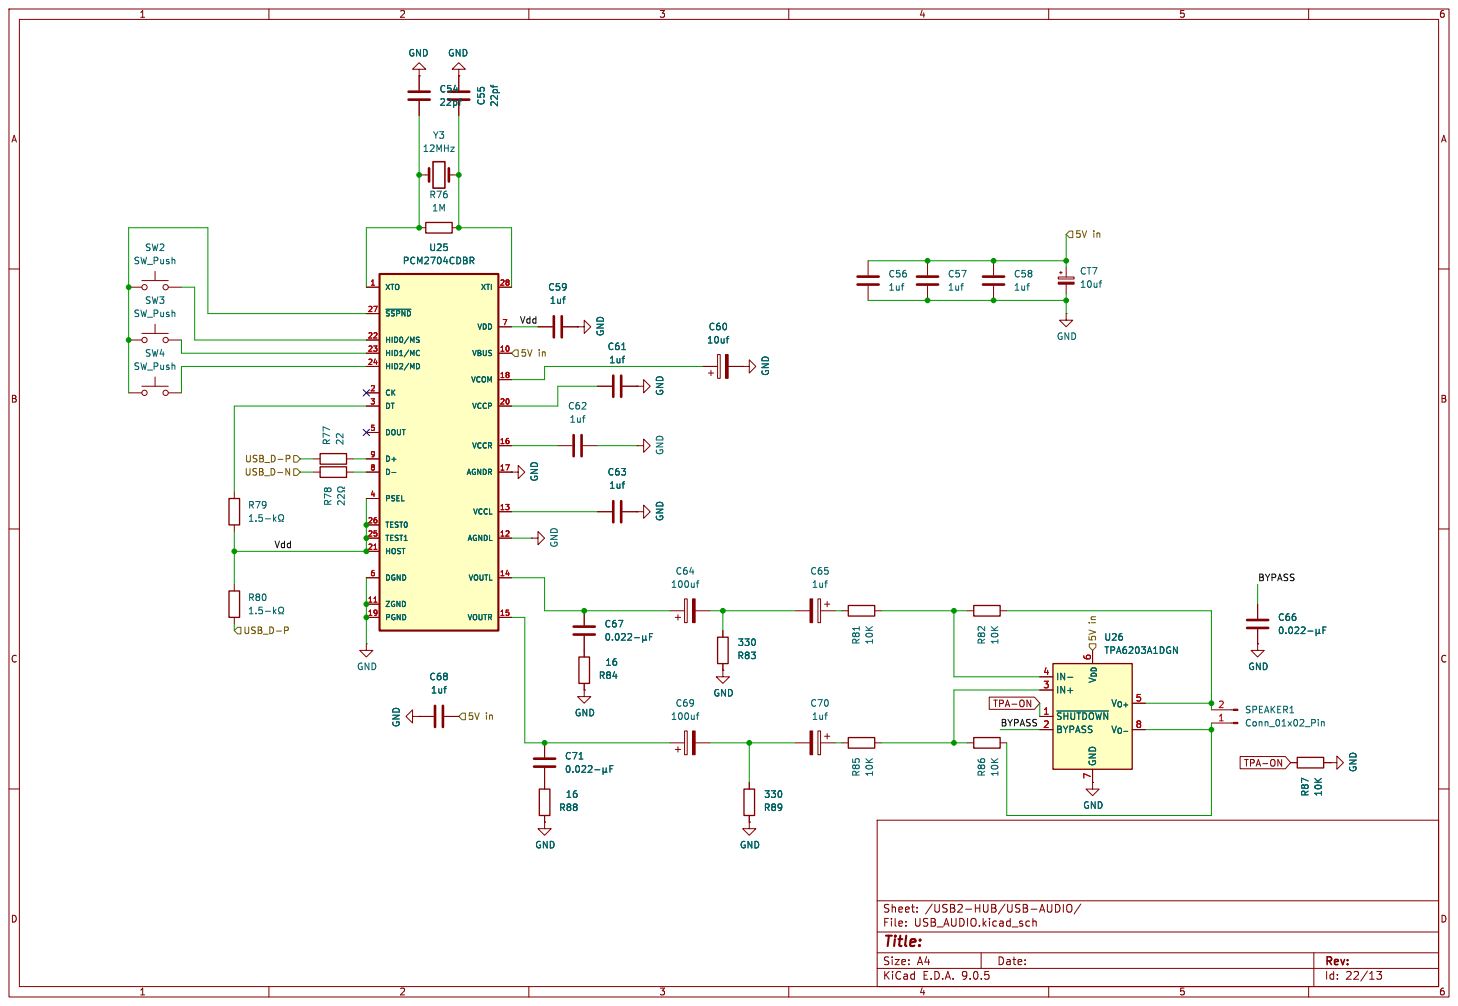
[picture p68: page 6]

Id: 22/13 Title: File: USB_AUDIO.kicad_sch Sheet: /USB2-HUB/USB-AUDIO/ C67
þÿ0.022-¼F GND

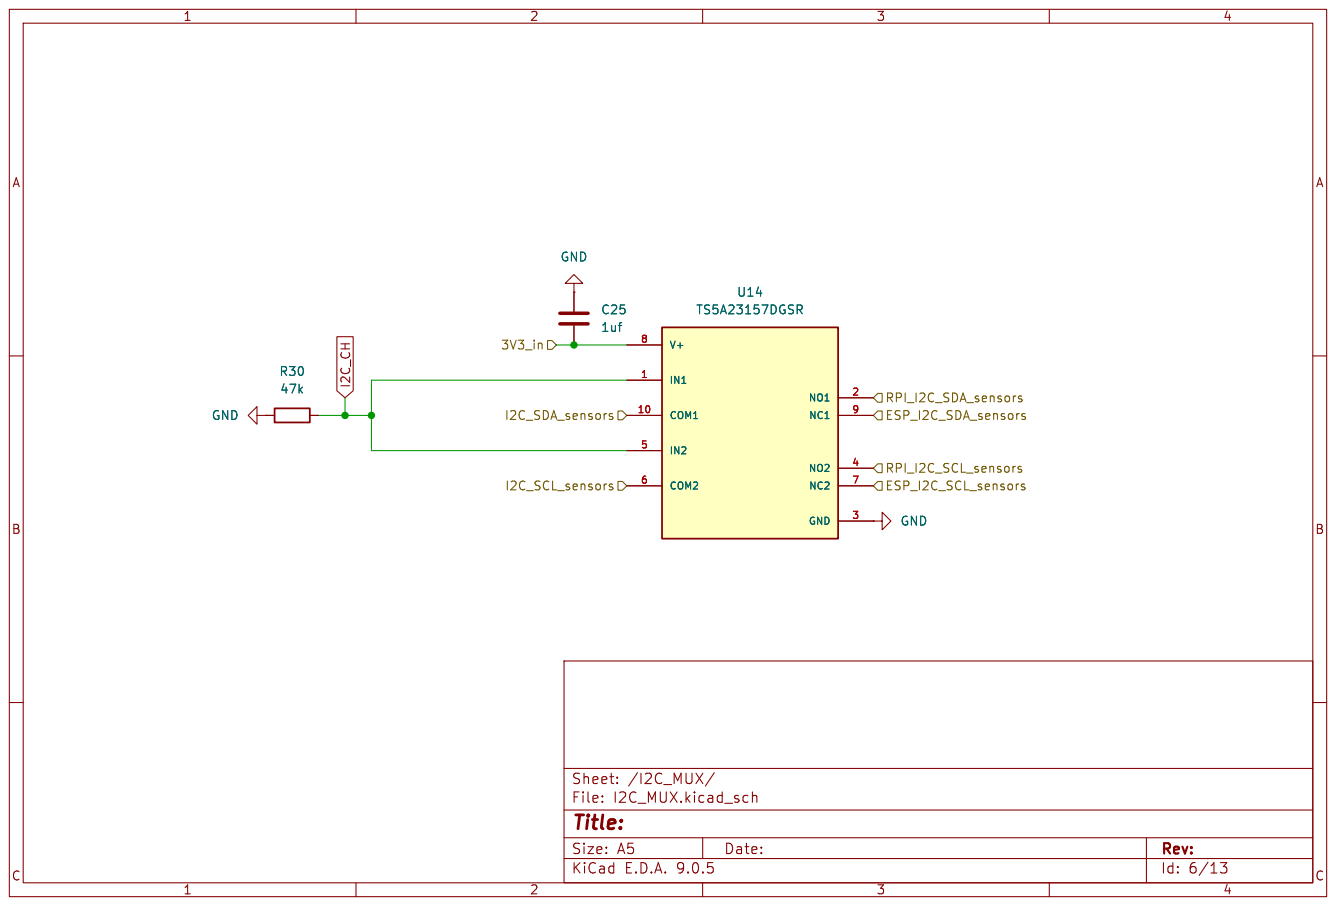
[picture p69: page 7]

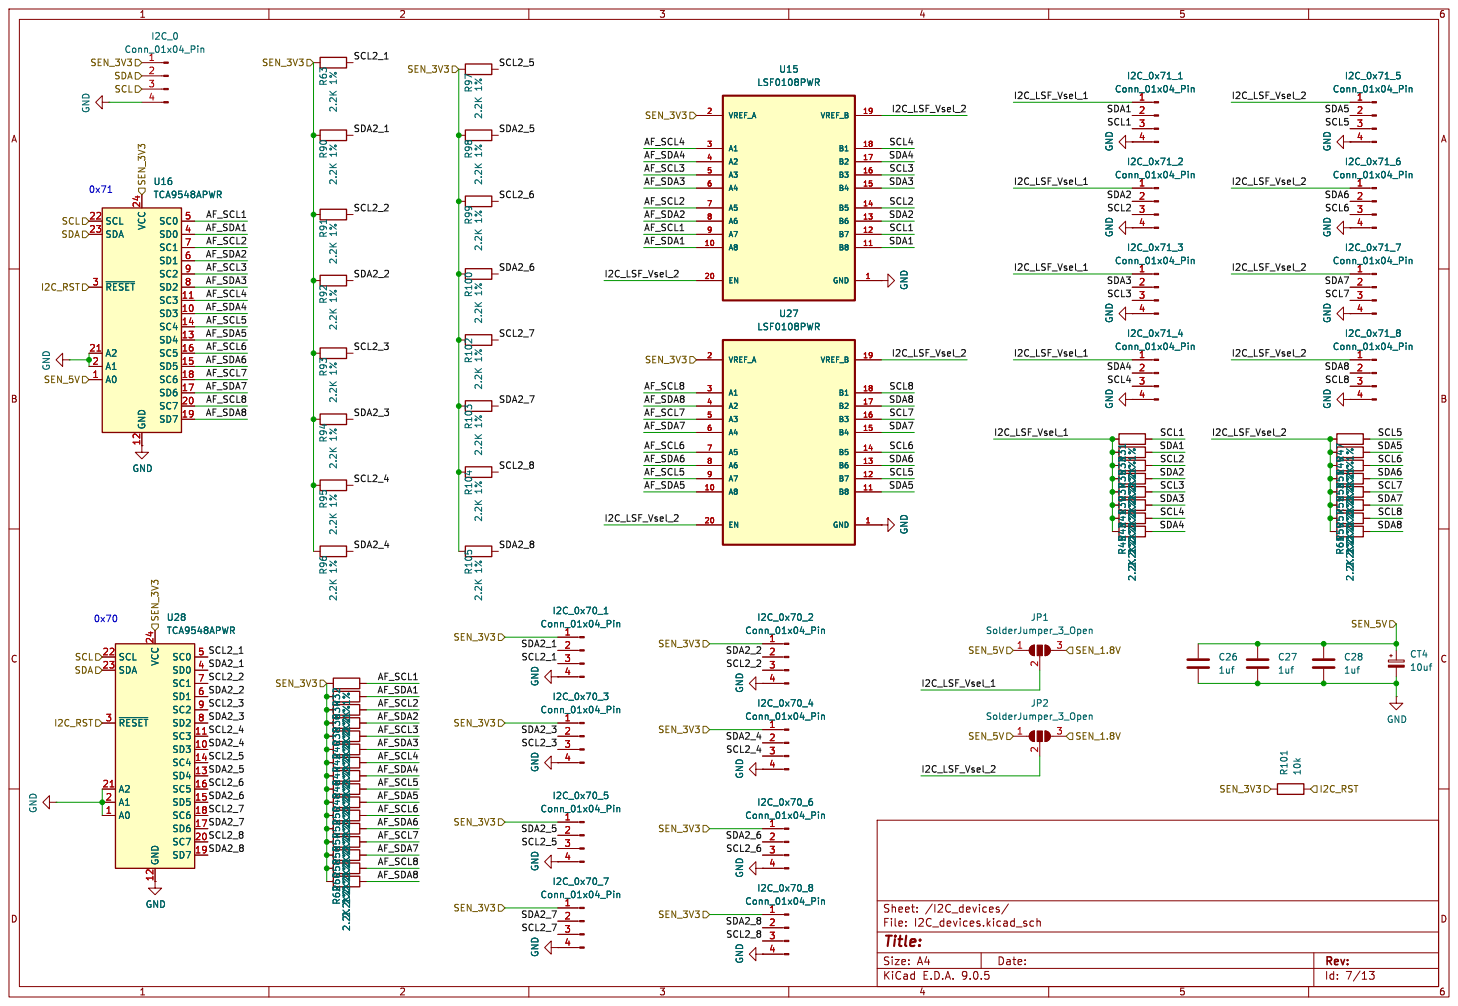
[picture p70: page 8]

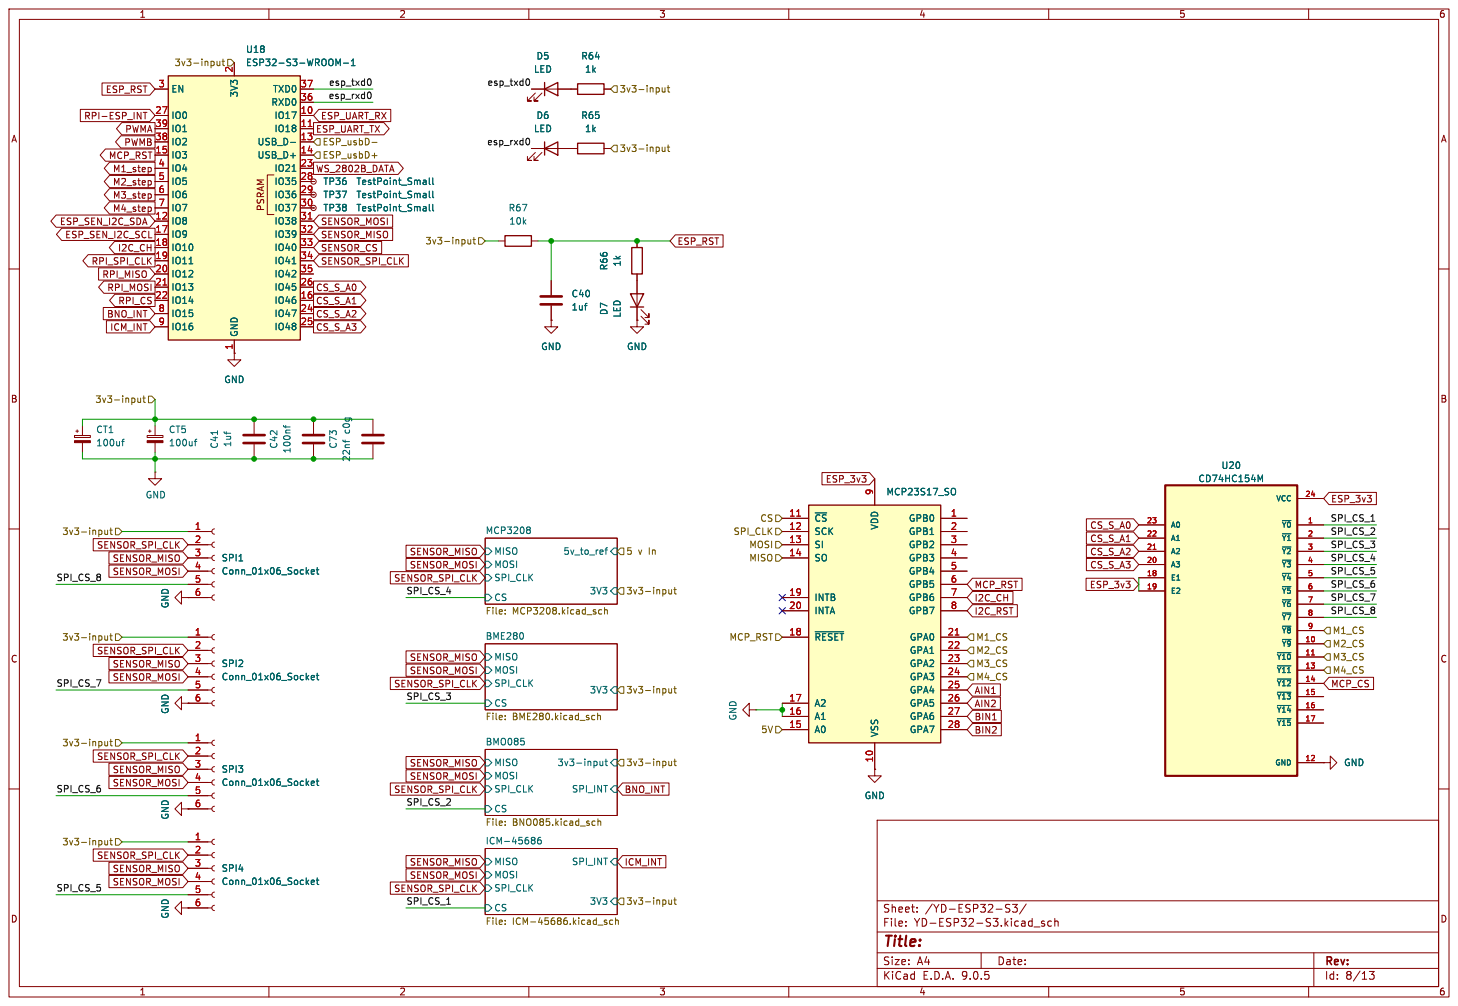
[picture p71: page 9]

BME280 File: BME280.kicad_sch CSMISO MOSI SPI_CLK
Id: 8/13 Title: File: YD-ESP32-S3.kicad_sch Sheet: /YD-ESP32-S3/ 3V3 CSMISO MOSI SPI_CLK

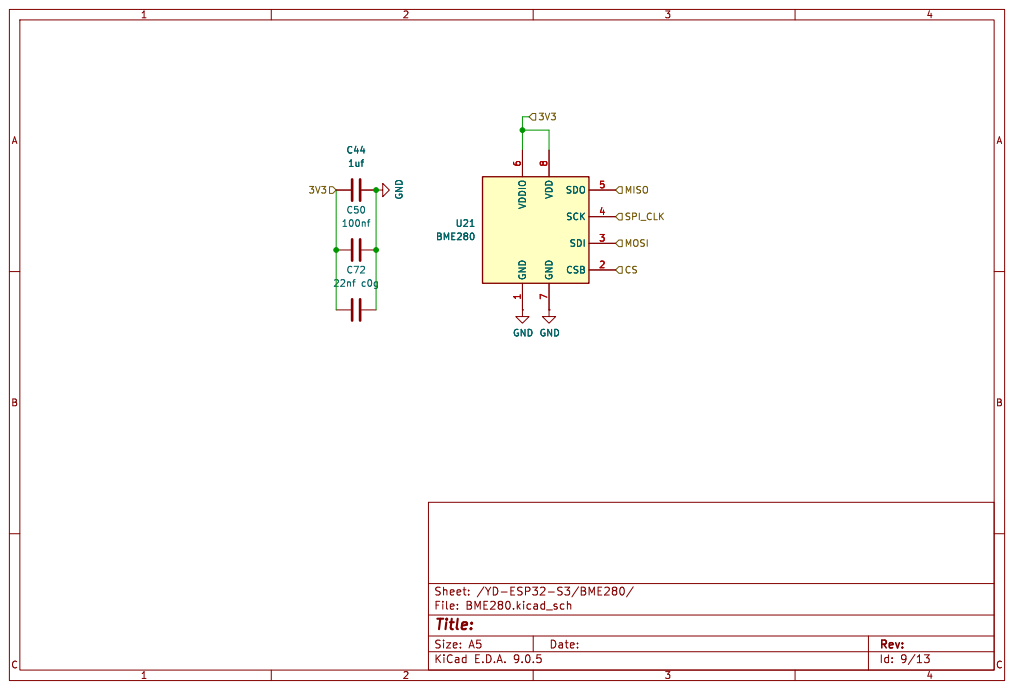
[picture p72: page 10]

7 SDO 5 SCK 4 SDI 3 CSB 2 U21 BME280 GND GND

7 SDO 5 SCK 4 SDI 3 CSB 2 GND GND

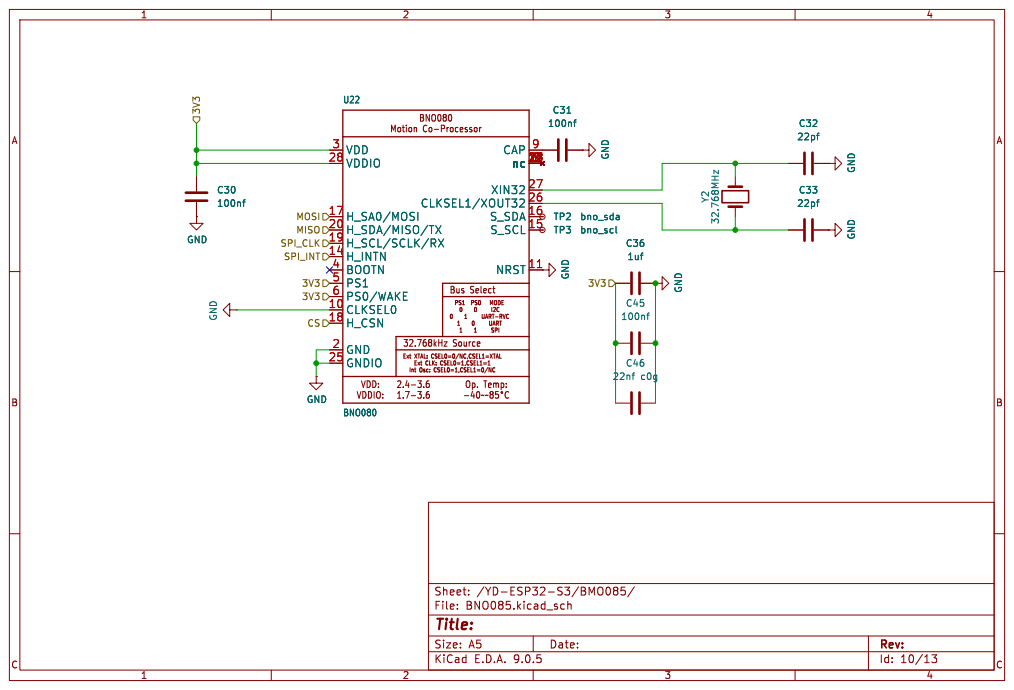
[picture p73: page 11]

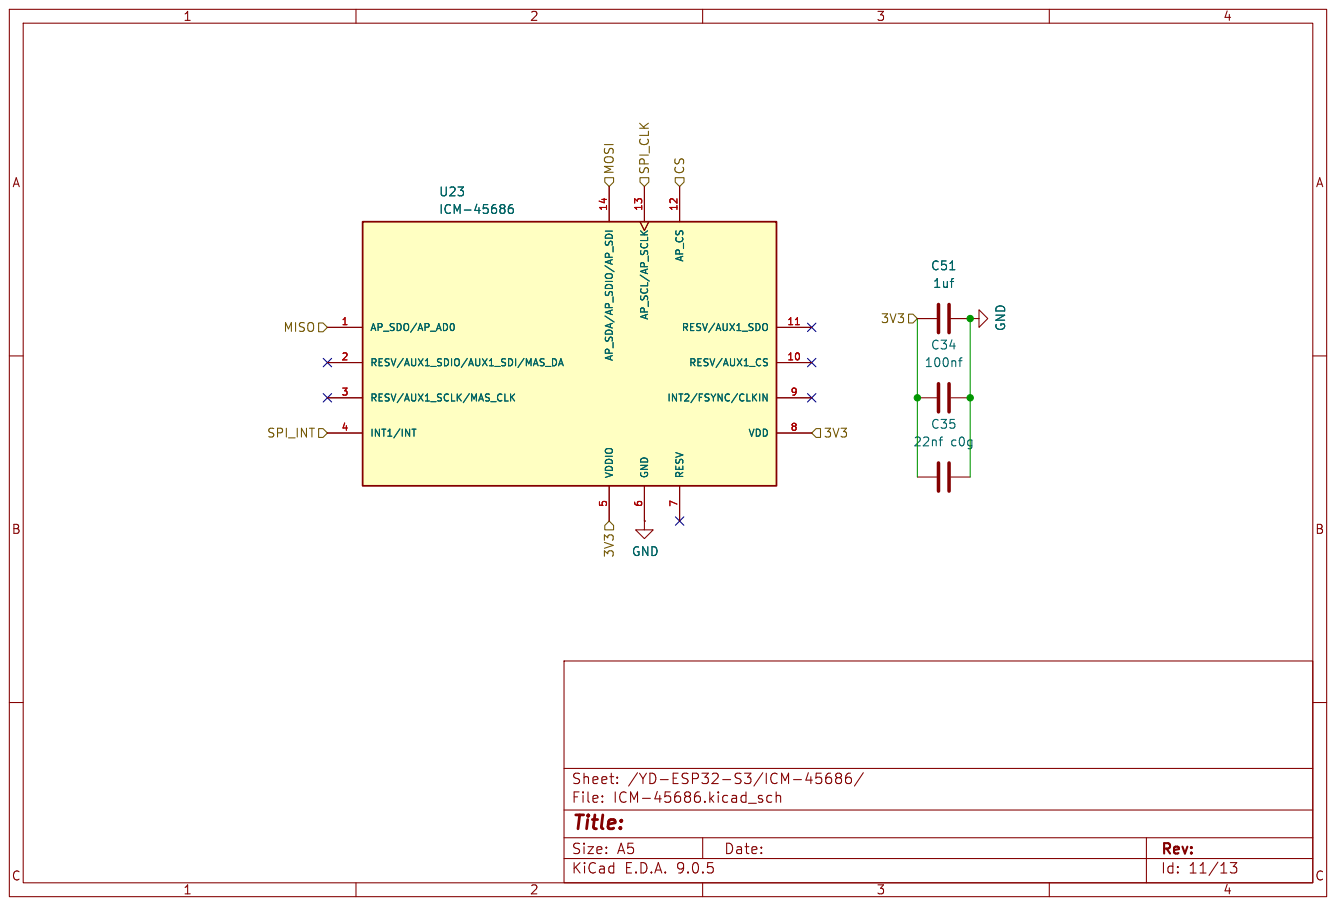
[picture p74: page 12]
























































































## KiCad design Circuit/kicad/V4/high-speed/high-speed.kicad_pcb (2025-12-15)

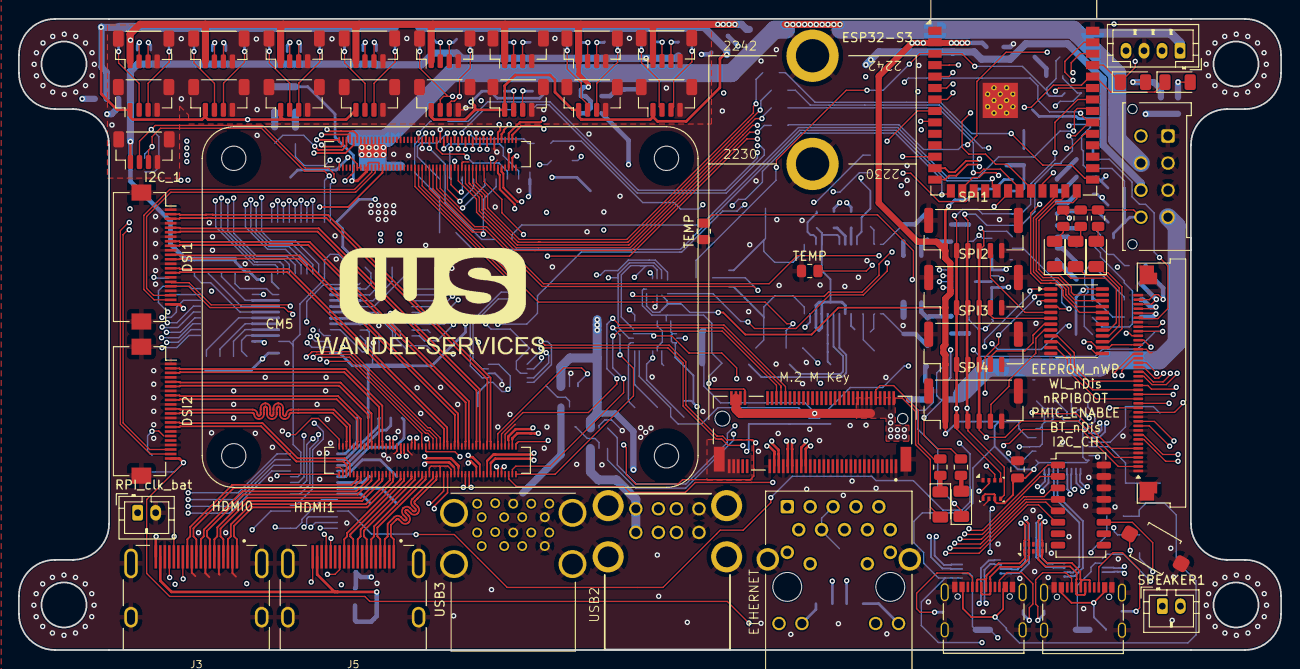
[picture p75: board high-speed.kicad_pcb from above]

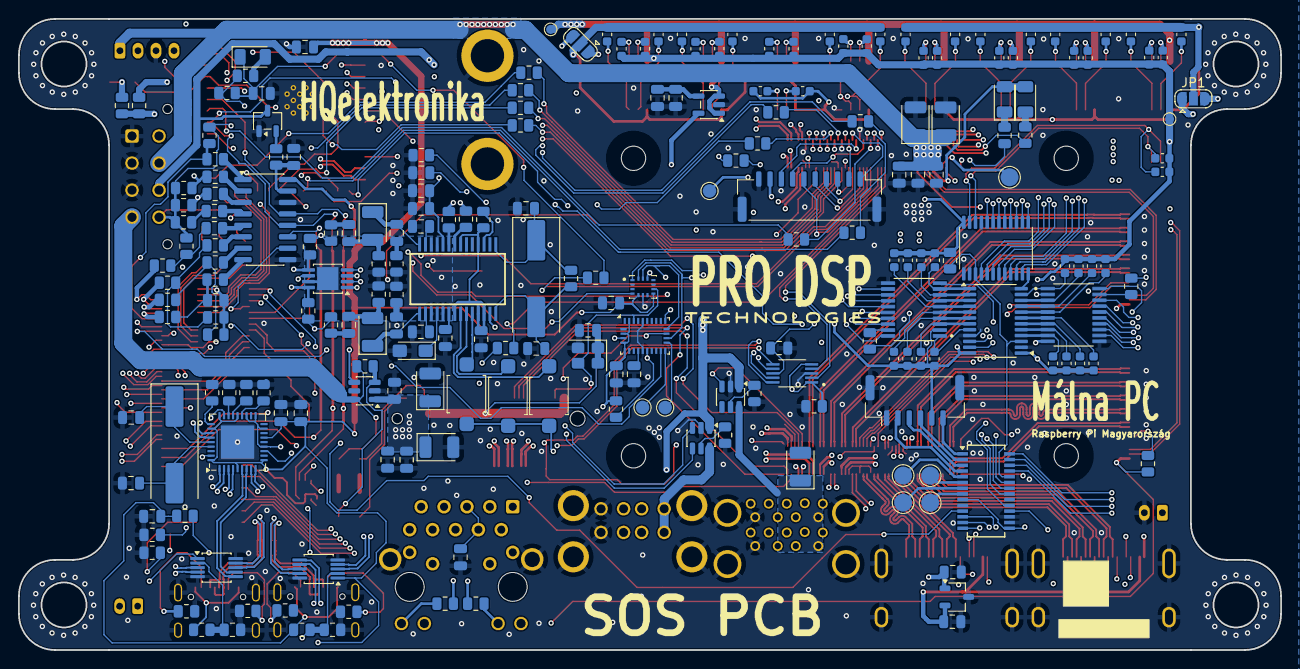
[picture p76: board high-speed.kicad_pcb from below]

Board: 6 copper layers, 140.0 x 70.0 mm, 274 parts (216 on the bottom side), 358 nets.

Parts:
C1, C2, C3, C7, C8, C13, C15, C18, C19, C21, C27, C36, C44, C59: 100nf; C_0805_2012Metric
C5, C6: 330pf; C_0805_2012Metric
C10, C66, C71: 100uF; CP_EIA-3528-21_Kemet-B
C14, C17, C24, C25, C28, C31, C61, C63, C64, C65, C67, C72: 1uf; C_0805_2012Metric
C16, C20, C58, C68, C69, C73: 22nf c0g; C_0805_2012Metric
C22, C23, C56, C57: 22pf; C_0805_2012Metric
C62: 10uF; CP_EIA-3216-18_Kemet-A_HandSolder
CM5: ComputeModule5-CM5; Raspberry-Pi-5-Compute-Module
CT1, CT2, CT3, CT4: 100uF; CP_EIA-3528-21_Kemet-B
D1, D2, D3, D4, D5, D6, D7, D8, D9, D10: LED; D_1206_3216Metric
DSI1: dsi; Hirose_FH12-22S-0.5SH_1x22-1MP_P0.50mm_Horizontal
DSI2: dsi1; Hirose_FH12-22S-0.5SH_1x22-1MP_P0.50mm_Horizontal
DSW1: SW_DIP_x08; SW_DIP_SPSTx08_Slide_Copal_CHS-08A_W5.08mm_P1.27mm_JPin
ESP32-S3: ESP32-S3-WROOM-1
I2C_0x70_1, I2C_0x70_2, I2C_0x70_3, I2C_0x70_4, I2C_0x70_5, I2C_0x70_6, I2C_0x70_7, I2C_0x70_8, I2C_0x71_1, I2C_0x71_2, I2C_0x71_3, I2C_0x71_4, I2C_0x71_5, I2C_0x71_6, I2C_0x71_7, I2C_0x71_8: Conn_01x04_Pin; JST_SH_BM04B-SRSS-TB_1x04-1MP_P1.00mm_Vertical
I2C_1: for default bus; JST_SH_BM04B-SRSS-TB_1x04-1MP_P1.00mm_Vertical
J1: Power Input; Molex_Micro-Fit_3.0_43045-0812_2x04_P3.00mm_Vertical
J2: from psu panel; Amphenol_F32Q-1A7x1-11040_1x40-1MP_P0.5mm_Horizontal
J3: HDMI0; EDAC 690-019-298-412
J5: HDMI1; EDAC 690-019-298-412
J6: RGB-BTN; JST_GH_BM06B-GHS-TBT_1x06-1MP_P1.25mm_Vertical
J7: MagJack-A70-112-331N126; TRJG0926HENL
J8: Fan; JST_PH_B4B-PH-K_1x04_P2.00mm_Vertical
J9: Conn_01x10_Socket; JST_GH_BM10B-GHS-TBT_1x10-1MP_P1.25mm_Vertical
J10: Bus_M.2_Socket_M; M.2 M Key socket
J11: USB_C_FLASH-RPI; USB_C_Receptacle_Palconn_UTC16-G
J12: USB_C_ESP; USB_C_Receptacle_Palconn_UTC16-G
JP1, JP3: SolderJumper_3_Open; SolderJumper-3_P1.3mm_Open_RoundedPad1.0x1.5mm
R1, R2, R3, R4: 0R; R_0805_2012Metric
R5, R30, R31: 2.2K; R_0805_2012Metric
R6, R40: 15K; R_0805_2012Metric
R7, R11, R15, R25, R93, R94, R96, R97, R98, R99, R102, R104, R106, R108, R110, R113, R116, R134, R136: 1K; R_0805_2012Metric
R8, R9: 470R; R_0805_2012Metric
R10, R12: 220R; R_0805_2012Metric
R13, R14, R16, R17, R18, R19, R20, R21, R119, R120: 22R; R_0805_2012Metric
R22, R23, R32, R33, R34, R85, R95, R101, R103, R105, R107, R109, R111, R114, R117, R124, R125, R128, R129, R130: 10K; R_0805_2012Metric
R24: 100R; R_0805_2012Metric
R26, R27, R28, R29: 5.1K; R_0805_2012Metric
R35: 12K; R_0805_2012Metric
R36, R37, R38, R39: 36K; R_0805_2012Metric
R41: 47K; R_0805_2012Metric
R42, R43, R44, R45, R46, R47, R48, R49, R50, R51, R52, R53, R54, R55, R56, R57, R58, R59, R60, R61, R62, R63, R64, R65, R66, R67, R68, R69, R70, R71, R72, R73, R74, R75, R76, R77, R78, R79, R80, R81, R82, R83, R84, R86, R87, R88, R89, R90, R91, R92: 2.2K; C_0603_1608Metric
R100: 10R; R_0805_2012Metric
R118: 1M; R_0805_2012Metric
R122: 1.5K; R_0805_2012Metric
R126, R132: 330R; R_0805_2012Metric
R127, R131: 16R; R_0805_2012Metric
R135: 10k; R_0805_2012Metric
R137, R138: 100k; R_0805_2012Metric
RPI_clk_bat: Battery_Cell; JST_PH_B2B-PH-K_1x02_P2.00mm_Vertical
SPEAKER1: Conn_01x02_Pin; JST_PH_B2B-PH-K_1x02_P2.00mm_Vertical
SPI1: spi1; JST_GH_BM06B-GHS-TBT_1x06-1MP_P1.25mm_Vertical
SPI2: spi2; JST_GH_BM06B-GHS-TBT_1x06-1MP_P1.25mm_Vertical
SPI3: spi3; JST_GH_BM06B-GHS-TBT_1x06-1MP_P1.25mm_Vertical
SPI4: spi4; JST_GH_BM06B-GHS-TBT_1x06-1MP_P1.25mm_Vertical
SW1, SW2, SW3, SW4: SW_Push; tact-smd sw
TEMP: 10K ntc; R_0805_2012Metric
TEMP#2: 10K ntc; R_0805_2012Metric
TP2: GPIO 16; TestPoint_Pad_D1.5mm
TP5: TestPoint; TestPoint_Pad_D2.0mm
TP9, TP10: TestPoint; TestPoint_Pad_D1.0mm
TP12: MCP_GPB_4; TestPoint_Pad_D2.0mm
TP13: MCP_GPB_5; TestPoint_Pad_D2.0mm
TP15: MCP_GPB_6; TestPoint_Pad_D2.0mm
TP16: MCP_GPB_7; TestPoint_Pad_D2.0mm
TP17: bno_sda; TestPoint_Pad_D1.5mm
TP18: bno_scl; TestPoint_Pad_D1.5mm
U1: TC1015-xCT; SOT-23-5
U2: RT9742SNGV; TSOT-23
U3, U13: AP22653W6; SOT-23-6
U6: AP22815AWU; SOT-23-6
U7: ASEK-32.768KHZ-L-R-T; Crystal_SMD_3225-4Pin_3.2x2.5mm
U8, U10: FSUSB42MUX; MSOP-10_3x3mm_P0.5mm
U9: TPD4EUSB30; USON-10_2.5x1.0mm_P0.5mm
U11: USB2514B-I/M2; QFN-36-1EP_6x6mm_P0.5mm_EP3.7x3.7mm
U14: TS5A23157DGSR; SOP50P490X110-10N
U15, U17: LSF0108PWR; SOP65P640X120-20N
U16, U18: TCA9548APWR; TSSOP-24_4.4x7.8mm_P0.65mm
U19: MCP23S17_SS; SSOP-28_3.9x9.9mm_P0.635mm
U20: CD74HC154M; TSSOP-24_4.4x7.8mm_P0.65mm
U21: XC6206P332MR; SOT-23-3
U22: MCP3208; SOIC-16_3.9x9.9mm_P1.27mm
U23: BME280; Bosch_LGA-8_2.5x2.5mm_P0.65mm_ClockwisePinNumbering
U24: BNO085; LGA-28_5.2x3.8mm_P0.5mm
U25: ICM-45686; IC_ICM-45686
U27: PCM2704CDBR; SSOP28
U28: TPA6203A1DGN; MSOP-8-1EP_3x3mm_P0.65mm_EP1.95x2.15mm_ThermalVias
USB2: ETHERNET; MOLEX_USB_67298-4090
USB3: USB3_A; MTCONN_UBAF30-D2011
Y1: 24MHz; Crystal_SMD_HC49-SD
Y2: 12MHz; Crystal_SMD_HC49-SD

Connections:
0NTC: R4.2, R117.2, R134.1
1NTC: R3.2, R114.2, R116.1
2NTC: R2.2, R111.2, R113.1
3NTC: R1.2, R109.2, R110.1
3V3_M.2: J1.4, R23.1, R24.1, U6.6 (IN)
32.768KHZ: J10.68 (SUSCLK), U7.3 (Out), U24.27 (XIN32), U25.9 (INT2/FSYNC/CLKIN)
/CM5_GPIO ( Ethernet, GPIOs)/+1.8v: CM5.88 (+1.8v_(Output)), CM5.90 (+1.8v_(Output)), TP5.1
/CM5_GPIO ( Ethernet, GPIOs)/+3.3v: CM5.78 (GPIO_VREF(1.8v/3.3v_Input)), CM5.84 (+3.3v_(Output)), CM5.86 (+3.3v_(Output)), D1.2 (A), D2.2 (A), DSI1.22, DSI2.22, J7.15 (LEDY_A), J7.17 (LEDG_A), J9.9, R5.1
/CM5_GPIO ( Ethernet, GPIOs)/BT_nDis: CM5.91 (BT_nDisable), DSW1.1
/CM5_GPIO ( Ethernet, GPIOs)/CAM_GPIO0: CM5.97 (CAM_GPIO0), DSI1.17
/CM5_GPIO ( Ethernet, GPIOs)/CAM_GPIO1: CM5.100 (CAM_GPIO1), DSI1.18
/CM5_GPIO ( Ethernet, GPIOs)/EEPROM_nWP: CM5.20 (EEPROM_nWP), DSW1.3
/CM5_GPIO ( Ethernet, GPIOs)/ETH_LEDG: CM5.17 (Ethernet_nLED2(3.3v)), R8.2
/CM5_GPIO ( Ethernet, GPIOs)/ETH_LEDY: CM5.15 (Ethernet_nLED3(3.3v)), R9.2
/CM5_GPIO ( Ethernet, GPIOs)/GPIO2: CM5.58 (GPIO2), U14.2 (NO1)
/CM5_GPIO ( Ethernet, GPIOs)/GPIO3: CM5.56 (GPIO3), U14.4 (NO2)
/CM5_GPIO ( Ethernet, GPIOs)/GPIO4: CM5.54 (GPIO4), R10.1
/CM5_GPIO ( Ethernet, GPIOs)/GPIO5: CM5.34 (GPIO5), R12.1
/CM5_GPIO ( Ethernet, GPIOs)/GPIO7: CM5.37 (GPIO7), J9.2
/CM5_GPIO ( Ethernet, GPIOs)/GPIO8: CM5.39 (GPIO8), J9.1
/CM5_GPIO ( Ethernet, GPIOs)/GPIO9: CM5.40 (GPIO9), J9.4
/CM5_GPIO ( Ethernet, GPIOs)/GPIO10: CM5.44 (GPIO10), J9.5
/CM5_GPIO ( Ethernet, GPIOs)/GPIO11: CM5.38 (GPIO11), J9.3
/CM5_GPIO ( Ethernet, GPIOs)/GPIO12: CM5.31 (GPIO12), R14.1
/CM5_GPIO ( Ethernet, GPIOs)/GPIO13: CM5.28 (GPIO13), R17.1
/CM5_GPIO ( Ethernet, GPIOs)/GPIO14: CM5.55 (GPIO14), R19.1
/CM5_GPIO ( Ethernet, GPIOs)/GPIO15: CM5.51 (GPIO15), R21.1
/CM5_GPIO ( Ethernet, GPIOs)/GPIO16: CM5.29 (GPIO16), TP2.1
/CM5_GPIO ( Ethernet, GPIOs)/GPIO17: CM5.50 (GPIO17), J9.6
/CM5_GPIO ( Ethernet, GPIOs)/GPIO18: CM5.49 (GPIO18), R20.1
/CM5_GPIO ( Ethernet, GPIOs)/GPIO19: CM5.26 (GPIO19), R18.1
/CM5_GPIO ( Ethernet, GPIOs)/GPIO20: CM5.27 (GPIO20), R16.1
/CM5_GPIO ( Ethernet, GPIOs)/GPIO21: CM5.25 (GPIO21), R13.1
/CM5_GPIO ( Ethernet, GPIOs)/GPIO24: CM5.45 (GPIO24), J9.7
/CM5_GPIO ( Ethernet, GPIOs)/GPIO25: CM5.41 (GPIO25), J9.8
/CM5_GPIO ( Ethernet, GPIOs)/GPIO26: CM5.24 (GPIO26), R11.1
/CM5_GPIO ( Ethernet, GPIOs)/GPIO27: CM5.48 (GPIO27), R136.1
/CM5_GPIO ( Ethernet, GPIOs)/ID_SC: CM5.35 (ID_SC), DSI2.20
/CM5_GPIO ( Ethernet, GPIOs)/ID_SD: CM5.36 (ID_SD), DSI2.21
/CM5_GPIO ( Ethernet, GPIOs)/PMIC_ENABLE: CM5.99 (PMIC_ENABLE), DSW1.2
/CM5_GPIO ( Ethernet, GPIOs)/PWM: CM5.19 (FAN_PWM), J8.2
/CM5_GPIO ( Ethernet, GPIOs)/PWR_BUT: CM5.92 (PWR_BUT), SW1.1
/CM5_GPIO ( Ethernet, GPIOs)/SCL0: CM5.80 (SCL0), DSI1.20
/CM5_GPIO ( Ethernet, GPIOs)/SDA0: CM5.82 (SDA0), DSI1.21
/CM5_GPIO ( Ethernet, GPIOs)/TACHO: CM5.16 (FAN_TACHO), J8.4
/CM5_GPIO ( Ethernet, GPIOs)/TRD0_N: CM5.10 (Ethernet_Pair0_N), J7.2 (TRD0-)
/CM5_GPIO ( Ethernet, GPIOs)/TRD0_P: CM5.12 (Ethernet_Pair0_P), J7.1 (TRD0+)
/CM5_GPIO ( Ethernet, GPIOs)/TRD1_N: CM5.6 (Ethernet_Pair1_N), J7.6 (TRD1-)
/CM5_GPIO ( Ethernet, GPIOs)/TRD1_P: CM5.4 (Ethernet_Pair1_P), J7.3 (TRD1+)
/CM5_GPIO ( Ethernet, GPIOs)/TRD2_N: CM5.9 (Ethernet_Pair2_N), J7.8 (TRD2-)
/CM5_GPIO ( Ethernet, GPIOs)/TRD2_P: CM5.11 (Ethernet_Pair2_P), J7.7 (TRD2+)
/CM5_GPIO ( Ethernet, GPIOs)/TRD3_N: CM5.5 (Ethernet_Pair3_N), J7.10 (TRD3-)
/CM5_GPIO ( Ethernet, GPIOs)/TRD3_P: CM5.3 (Ethernet_Pair3_P), J7.9 (TRD3+)
/CM5_GPIO ( Ethernet, GPIOs)/WL_nDis: CM5.89 (WiFi_nDisable), DSW1.5
/CM5_GPIO ( Ethernet, GPIOs)/nRPIBOOT: CM5.93 (nRPIBOOT), DSW1.4
/CM5_HighSpeed/DPHY0_C_N: CM5.127 (MIPI0_C_N), DSI1.8
/CM5_HighSpeed/DPHY0_C_P: CM5.129 (MIPI0_C_P), DSI1.9
/CM5_HighSpeed/DPHY0_D0_N: CM5.115 (MIPI0_D0_N), DSI1.2
/CM5_HighSpeed/DPHY0_D0_P: CM5.117 (MIPI0_D0_P), DSI1.3
/CM5_HighSpeed/DPHY0_D1_N: CM5.121 (MIPI0_D1_N), DSI1.5
/CM5_HighSpeed/DPHY0_D1_P: CM5.123 (MIPI0_D1_P), DSI1.6
/CM5_HighSpeed/DPHY0_D2_N: CM5.133 (MIPI0_D2_N), DSI1.11
/CM5_HighSpeed/DPHY0_D2_P: CM5.135 (MIPI0_D2_P), DSI1.12
/CM5_HighSpeed/DPHY0_D3_N: CM5.139 (MIPI0_D3_N), DSI1.14
/CM5_HighSpeed/DPHY0_D3_P: CM5.141 (MIPI0_D3_P), DSI1.15
/CM5_HighSpeed/DPHY1_C_N: CM5.187 (MIPI1_C_N), DSI2.8
/CM5_HighSpeed/DPHY1_C_P: CM5.189 (MIPI1_C_P), DSI2.9
/CM5_HighSpeed/DPHY1_D0_N: CM5.175 (MIPI1_D0_N), DSI2.2
/CM5_HighSpeed/DPHY1_D0_P: CM5.177 (MIPI1_D0_P), DSI2.3
/CM5_HighSpeed/DPHY1_D1_N: CM5.181 (MIPI1_D1_N), DSI2.5
/CM5_HighSpeed/DPHY1_D1_P: CM5.183 (MIPI1_D1_P), DSI2.6
/CM5_HighSpeed/DPHY1_D2_N: CM5.193 (MIPI1_D2_N), DSI2.11
/CM5_HighSpeed/DPHY1_D2_P: CM5.195 (MIPI1_D2_P), DSI2.12
/CM5_HighSpeed/DPHY1_D3_N: CM5.194 (MIPI1_D3_N), DSI2.14
/CM5_HighSpeed/DPHY1_D3_P: CM5.196 (MIPI1_D3_P), DSI2.15
/CM5_HighSpeed/HDMI0_CEC: CM5.151 (HDMI0_CEC), J3.13 (CEC)
/CM5_HighSpeed/HDMI0_CK_N: CM5.190 (HDMI0_CLK_N), J3.12 (CK-)
/CM5_HighSpeed/HDMI0_CK_P: CM5.188 (HDMI0_CLK_P), J3.10 (CK+)
/CM5_HighSpeed/HDMI0_D0_N: CM5.184 (HDMI0_TX0_N), J3.9 (D0-)
/CM5_HighSpeed/HDMI0_D0_P: CM5.182 (HDMI0_TX0_P), J3.7 (D0+)
/CM5_HighSpeed/HDMI0_D1_N: CM5.178 (HDMI0_TX1_N), J3.6 (D1-)
/CM5_HighSpeed/HDMI0_D1_P: CM5.176 (HDMI0_TX1_P), J3.4 (D1+)
/CM5_HighSpeed/HDMI0_D2_N: CM5.172 (HDMI0_TX2_N), J3.3 (D2-)
/CM5_HighSpeed/HDMI0_D2_P: CM5.170 (HDMI0_TX2_P), J3.1 (D2+)
/CM5_HighSpeed/HDMI0_HOTPLUG: CM5.153 (HDMI0_HOTPLUG), J3.19 (HPD/HEAC-)
/CM5_HighSpeed/HDMI0_SCL: CM5.200 (HDMI0_SCL), J3.15 (SCL)
/CM5_HighSpeed/HDMI0_SDA: CM5.199 (HDMI0_SDA), J3.16 (SDA)
/CM5_HighSpeed/HDMI1_CEC: CM5.149 (HDMI1_CEC), J5.13 (CEC)
/CM5_HighSpeed/HDMI1_CK_N: CM5.166 (HDMI1_CLK_N), J5.12 (CK-)
/CM5_HighSpeed/HDMI1_CK_P: CM5.164 (HDMI1_CLK_P), J5.10 (CK+)
/CM5_HighSpeed/HDMI1_D0_N: CM5.160 (HDMI1_TX0_N), J5.9 (D0-)
/CM5_HighSpeed/HDMI1_D0_P: CM5.158 (HDMI1_TX0_P), J5.7 (D0+)
/CM5_HighSpeed/HDMI1_D1_N: CM5.154 (HDMI1_TX1_N), J5.6 (D1-)
/CM5_HighSpeed/HDMI1_D1_P: CM5.152 (HDMI1_TX1_P), J5.4 (D1+)
/CM5_HighSpeed/HDMI1_D2_N: CM5.148 (HDMI1_TX2_N), J5.3 (D2-)
/CM5_HighSpeed/HDMI1_D2_P: CM5.146 (HDMI1_TX2_P), J5.1 (D2+)
/CM5_HighSpeed/HDMI1_HOTPLUG: CM5.143 (HDMI1_HOTPLUG), J5.19 (HPD/HEAC-)
/CM5_HighSpeed/HDMI1_SCL: CM5.147 (HDMI1_SCL), J5.15 (SCL)
/CM5_HighSpeed/HDMI1_SDA: CM5.145 (HDMI1_SDA), J5.16 (SDA)
/CM5_HighSpeed/HDMI_5v: C8.1, J3.18 (+5V), J5.18 (+5V), U2.2 (OUT)
/CM5_HighSpeed/PCIE_CLK_N: CM5.112 (PCIe_CLK_N), J10.53 (REFCLKn)
/CM5_HighSpeed/PCIE_CLK_P: CM5.110 (PCIe_CLK_P), J10.55 (REFCLKp)
/CM5_HighSpeed/PCIE_PWR_EN: CM5.106 (PCIE_PWR_EN), U6.4 (EN)
/CM5_HighSpeed/PCIE_RX_N: CM5.118 (PCIe_RX_N), J10.43 (PETp0)
/CM5_HighSpeed/PCIE_RX_P: CM5.116 (PCIe_RX_P), J10.41 (PETn0)
/CM5_HighSpeed/PCIE_TX_N: CM5.124 (PCIe_TX_N), J10.49 (PERp0)
/CM5_HighSpeed/PCIE_TX_P: CM5.122 (PCIe_TX_P), J10.47 (PERn0)
/CM5_HighSpeed/PCIE_nCLKREQ: CM5.102 (PCIe_nCLKREQ), J10.52 (~CLKREQ)
/CM5_HighSpeed/PCIE_nRST: CM5.109 (PCIe_nRST), J10.50 (~PERST)
/CM5_HighSpeed/PCIE_nWAKE: CM5.104 (PCIE_nWAKE), J10.54 (~PEWAKE)
/CM5_HighSpeed/USB2_N: CM5.103 (USB2_N), U8.4 (D_N)
/CM5_HighSpeed/USB2_P: CM5.105 (USB2_P), U8.3 (D_P)
/CM5_HighSpeed/USB3-0-D_N: CM5.136 (USB3-0-D_N), USB3.A2 (D-)
/CM5_HighSpeed/USB3-0-D_P: CM5.134 (USB3-0-D_P), USB3.A3 (D+)
/CM5_HighSpeed/USB3-0-RX_N: CM5.128 (USB3-0-RX_N), USB3.A6 (SSRX+)
/CM5_HighSpeed/USB3-0-RX_P: CM5.130 (USB3-0-RX_P), USB3.A5 (SSRX-)
/CM5_HighSpeed/USB3-0-TX_N: CM5.140 (USB3-0-TX_N), USB3.A9 (SSTX+)
/CM5_HighSpeed/USB3-0-TX_P: CM5.142 (USB3-0-TX_P), USB3.A8 (SSTX-)
/CM5_HighSpeed/USB3-1-D_N: CM5.165 (USB3-1-D_N), USB3.B2 (D-)
/CM5_HighSpeed/USB3-1-D_P: CM5.163 (USB3-1-D_P), USB3.B3 (D+)
/CM5_HighSpeed/USB3-1-RX_N: CM5.157 (USB3-1-RX_N), USB3.B6 (SSRX+)
/CM5_HighSpeed/USB3-1-RX_P: CM5.159 (USB3-1-RX_P), USB3.B5 (SSRX-)
/CM5_HighSpeed/USB3-1-TX_N: CM5.169 (USB3-1-TX_N), USB3.B9 (SSTX+)
/CM5_HighSpeed/USB3-1-TX_P: CM5.171 (USB3-1-TX_P), USB3.B8 (SSTX-)
/CM5_HighSpeed/USBOTG_ID: CM5.101 (USB_OTG_ID), R30.2, R32.1, U8.2 (SEL)
/CM5_HighSpeed/VBUS: C10.1, U3.6 (OUT), USB3.A1 (VBUS), USB3.B1 (VBUS)
/CM5_HighSpeed/VBUS_EN: CM5.111 (VBUS_EN), U3.3 (EN)
/I2C_CH: DSW1.6, R41.2, U14.1 (IN1), U14.5 (IN2), U19.23 (GPA2)
/I2C_MUX/ESP_I2C_SCL_sensors: ESP32-S3.17 (IO9), U14.7 (NC2)
/I2C_MUX/ESP_I2C_SDA_sensors: ESP32-S3.12 (IO8), U14.9 (NC1)
/I2C_MUX/I2C_SCL_sensors: I2C_1.3, J2.9, R75.2, U14.6 (COM2), U16.22 (SCL), U18.22 (SCL)
/I2C_MUX/I2C_SDA_sensors: I2C_1.2, J2.8, R64.2, U14.10 (COM1), U16.23 (SDA), U18.23 (SDA)
/I2C_RST: R85.2, U16.3 (~RESET), U18.3 (~RESET), U19.24 (GPA3)
/I2C_devices/I2C_LSF_Vsel_1: I2C_0x71_1.1, I2C_0x71_2.1, I2C_0x71_3.1, I2C_0x71_4.1, JP1.2 (C), R54.1, R56.1, R58.1, R61.1, R65.1, R67.1, R69.1, R71.1, R137.2, U15.10 (EN)
/I2C_devices/I2C_LSF_Vsel_2: I2C_0x71_5.1, I2C_0x71_6.1, I2C_0x71_7.1, I2C_0x71_8.1, JP3.2 (C), R55.1, R57.1, R59.1, R62.1, R66.1, R68.1, R70.1, R72.1, R138.2, U17.10 (EN)
/I2C_devices/SEN_1V8: JP1.3 (B), JP3.3 (B), U1.5 (VOUT)
/I2C_devices/Voltage_level_translation/In_SCL1: R76.2, U15.8 (A7), U16.5 (SC0)
/I2C_devices/Voltage_level_translation/In_SCL2: R78.2, U15.6 (A5), U16.7 (SC1)
/I2C_devices/Voltage_level_translation/In_SCL3: R80.2, U15.4 (A3), U16.9 (SC2)
/I2C_devices/Voltage_level_translation/In_SCL4: R82.2, U15.1 (A1), U16.11 (SC3)
/I2C_devices/Voltage_level_translation/In_SCL5: R84.2, U16.14 (SC4), U17.8 (A7)
/I2C_devices/Voltage_level_translation/In_SCL6: R87.2, U16.16 (SC5), U17.6 (A5)
/I2C_devices/Voltage_level_translation/In_SCL7: R89.2, U16.18 (SC6), U17.4 (A3)
/I2C_devices/Voltage_level_translation/In_SCL8: R91.2, U16.20 (SC7), U17.1 (A1)
/I2C_devices/Voltage_level_translation/In_SDA1: R77.2, U15.9 (A8), U16.4 (SD0)
/I2C_devices/Voltage_level_translation/In_SDA2: R79.2, U15.7 (A6), U16.6 (SD1)
/I2C_devices/Voltage_level_translation/In_SDA3: R81.2, U15.5 (A4), U16.8 (SD2)
/I2C_devices/Voltage_level_translation/In_SDA4: R83.2, U15.3 (A2), U16.10 (SD3)
/I2C_devices/Voltage_level_translation/In_SDA5: R86.2, U16.13 (SD4), U17.9 (A8)
/I2C_devices/Voltage_level_translation/In_SDA6: R88.2, U16.15 (SD5), U17.7 (A6)
/I2C_devices/Voltage_level_translation/In_SDA7: R90.2, U16.17 (SD6), U17.5 (A4)
/I2C_devices/Voltage_level_translation/In_SDA8: R92.2, U16.19 (SD7), U17.3 (A2)
/I2C_devices/Voltage_level_translation/SCL1: I2C_0x71_1.3, R69.2, U15.13 (B7)
/I2C_devices/Voltage_level_translation/SCL2: I2C_0x71_2.3, R65.2, U15.15 (B5)
/I2C_devices/Voltage_level_translation/SCL3: I2C_0x71_3.3, R58.2, U15.17 (B3)
/I2C_devices/Voltage_level_translation/SCL4: I2C_0x71_4.3, R54.2, U15.20 (B1)
/I2C_devices/Voltage_level_translation/SCL5: I2C_0x71_5.3, R70.2, U17.13 (B7)
/I2C_devices/Voltage_level_translation/SCL6: I2C_0x71_6.3, R66.2, U17.15 (B5)
/I2C_devices/Voltage_level_translation/SCL7: I2C_0x71_7.3, R59.2, U17.17 (B3)
/I2C_devices/Voltage_level_translation/SCL8: I2C_0x71_8.3, R55.2, U17.20 (B1)
/I2C_devices/Voltage_level_translation/SDA1: I2C_0x71_1.2, R71.2, U15.12 (B8)
/I2C_devices/Voltage_level_translation/SDA2: I2C_0x71_2.2, R67.2, U15.14 (B6)
/I2C_devices/Voltage_level_translation/SDA3: I2C_0x71_3.2, R61.2, U15.16 (B4)
/I2C_devices/Voltage_level_translation/SDA4: I2C_0x71_4.2, R56.2, U15.18 (B2)
/I2C_devices/Voltage_level_translation/SDA5: I2C_0x71_5.2, R72.2, U17.12 (B8)
/I2C_devices/Voltage_level_translation/SDA6: I2C_0x71_6.2, R68.2, U17.14 (B6)
/I2C_devices/Voltage_level_translation/SDA7: I2C_0x71_7.2, R62.2, U17.16 (B4)
/I2C_devices/Voltage_level_translation/SDA8: I2C_0x71_8.2, R57.2, U17.18 (B2)
/I2C_devices/multiplexer_0x70/SCL1: I2C_0x70_1.3, R49.2, U18.10 (SD3)
/I2C_devices/multiplexer_0x70/SCL2: I2C_0x70_2.3, R47.2, U18.8 (SD2)
/I2C_devices/multiplexer_0x70/SCL3: I2C_0x70_3.3, R45.2, U18.6 (SD1)
/I2C_devices/multiplexer_0x70/SCL4: I2C_0x70_4.3, R43.2, U18.4 (SD0)
/I2C_devices/multiplexer_0x70/SCL5: I2C_0x70_5.3, R50.2, U18.14 (SC4)
/I2C_devices/multiplexer_0x70/SCL6: I2C_0x70_6.3, R52.2, U18.16 (SC5)
/I2C_devices/multiplexer_0x70/SCL7: I2C_0x70_7.3, R60.2, U18.18 (SC6)
/I2C_devices/multiplexer_0x70/SCL8: I2C_0x70_8.3, R73.2, U18.20 (SC7)
/I2C_devices/multiplexer_0x70/SDA1: I2C_0x70_1.2, R48.2, U18.11 (SC3)
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

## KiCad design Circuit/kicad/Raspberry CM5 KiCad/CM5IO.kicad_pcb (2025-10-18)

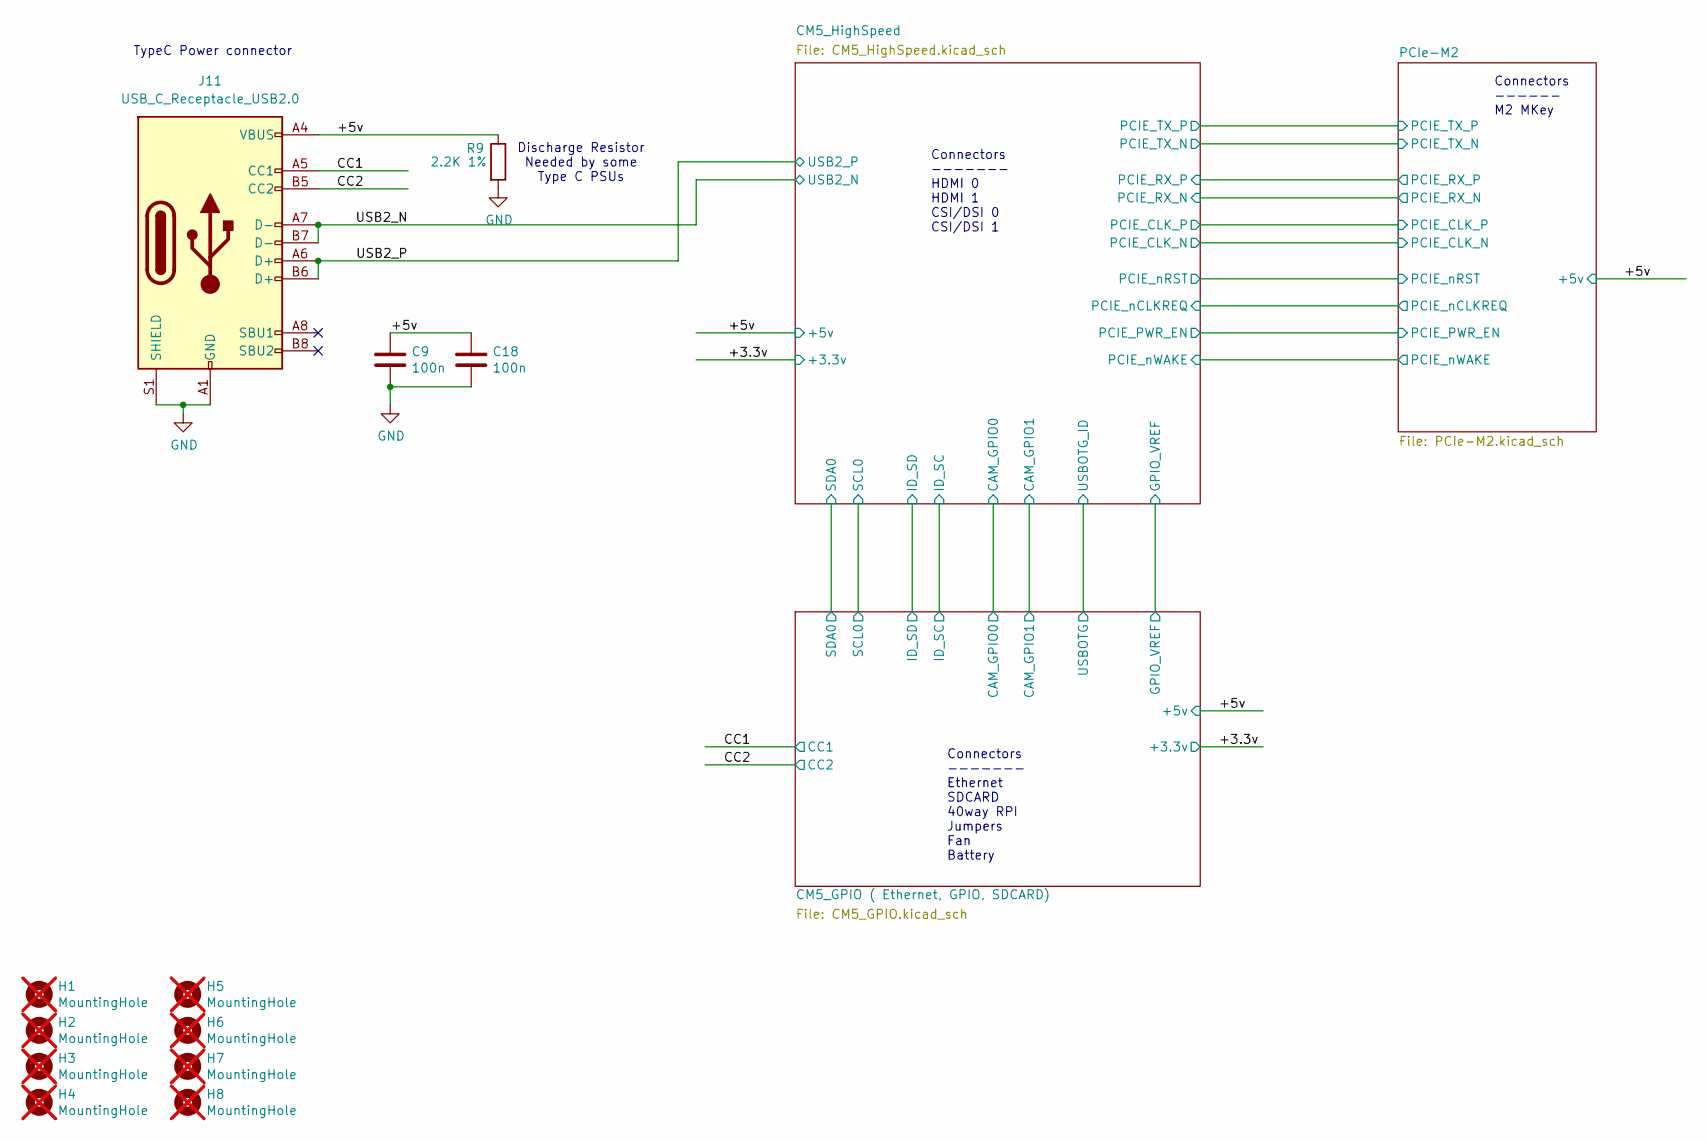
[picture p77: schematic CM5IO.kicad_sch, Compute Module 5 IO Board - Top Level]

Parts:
C9, C18: 100n; C_0402_1005Metric; Part Description 0.1uF 10% 16V Ceramic Capacitor X7R 040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
H1, H2, H3, H4, H5, H6, H7, H8: MountingHole; MountingHole_2.7mm_M2.5_DIN965; Part Description M2.5 mounting hole; not fitted
J11: USB_C_Receptacle_USB2.0; USB_C_Receptacle_GCT_USB4105-xx-A_16P_TopMnt_Horizontal; Part Description USBC USB2 data and power connector
R9: 2.2K 1%; R_0402_1005Metric; Part Description Resistor 2.2K M1005 1% 63mW

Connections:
/+5v: C9.1, C18.1, J11.A4 (VBUS), J11.A9 (VBUS), J11.B4 (VBUS), J11.B9 (VBUS), R9.1; also elsewhere on the board
/CC1: J11.A5 (CC1); also elsewhere on the board
/CC2: J11.B5 (CC2); also elsewhere on the board
/USB2_N: J11.A7 (D-), J11.B7 (D-); also elsewhere on the board
/USB2_P: J11.A6 (D+), J11.B6 (D+); also elsewhere on the board
GND: C9.2, C18.2, J11.A1 (GND), J11.A12 (GND), J11.B1 (GND), J11.B12 (GND), J11.S1 (SHIELD), R9.2; also elsewhere on the board

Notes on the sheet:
Connectors ------- Ethernet SDCARD 40way RPI Jumpers Fan Battery
Connectors ------ M2 MKey
Discharge Resistor Needed by some Type C PSUs
TypeC Power connector
Connectors ------- HDMI 0 HDMI 1 CSI/DSI 0 CSI/DSI 1

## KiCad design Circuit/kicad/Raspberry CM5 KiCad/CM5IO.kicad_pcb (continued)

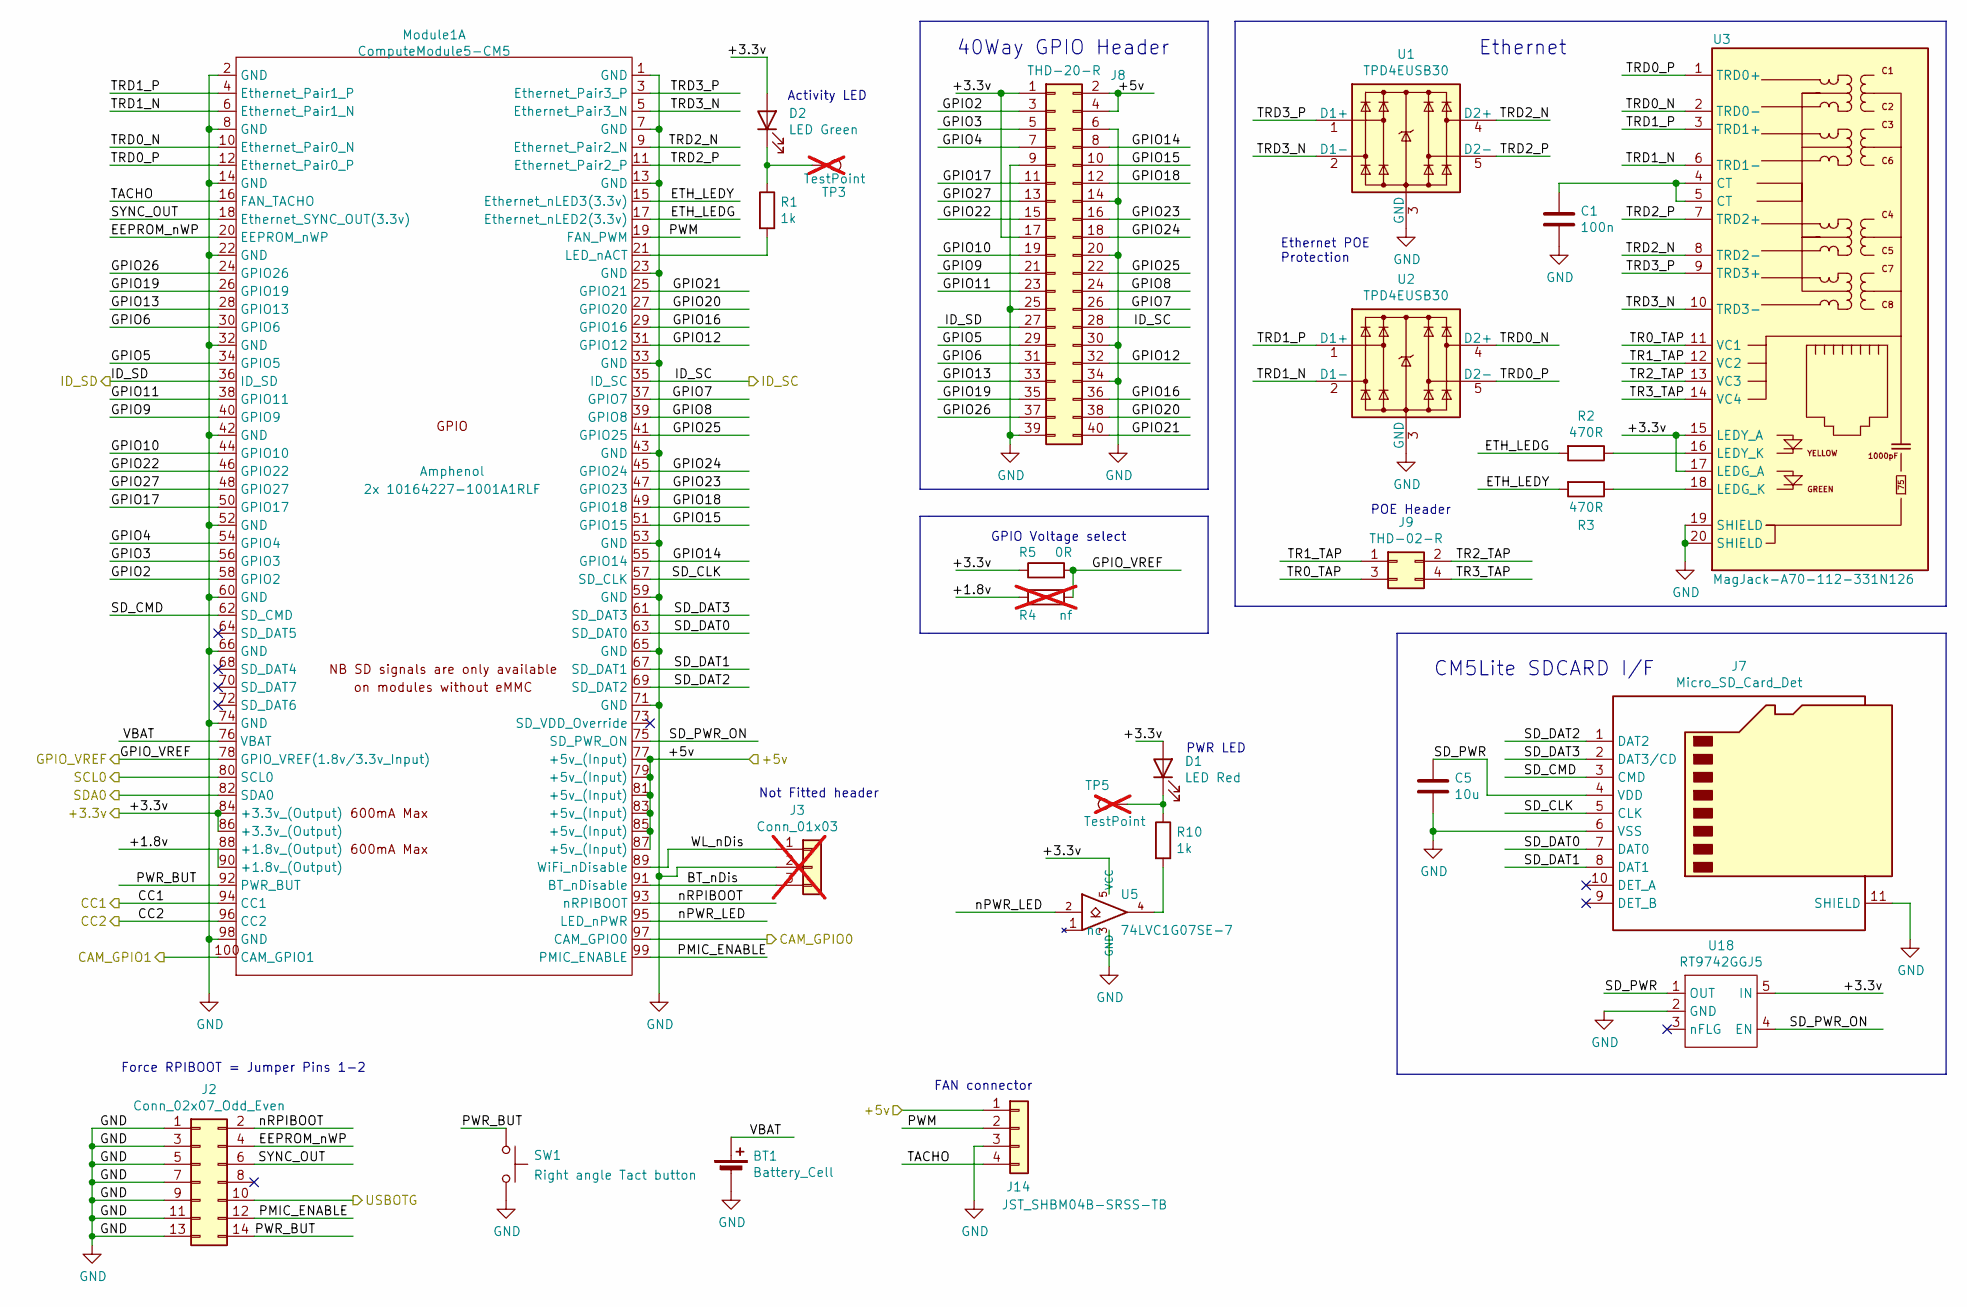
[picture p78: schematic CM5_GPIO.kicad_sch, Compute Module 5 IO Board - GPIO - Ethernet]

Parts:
BT1: Battery_Cell; BatteryHolder_Keystone_3034_1x20mm; Part Description Battery Retainer Coin, 20.0mm 1 Cell SM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
C1: 100n; C_0402_1005Metric; Part Description 0.1uF 10% 16V Ceramic Capacitor X7R 040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
C5: 10u; C_0805_2012Metric; Part Description 10uF 10% 10V Ceramic Capacitor X7R 0805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
D1: LED Red; LED_0603_1608Metric; Part Description Red 620nm LED Indication - Discrete 2.2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
D2: LED Green; LED_0603_1608Metric; Part Description Green 572nm LED Indication - Discrete 2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
J2: Conn_02x07_Odd_Even; PinHeader_2x07_P2.54mm_Vertical; Part Description PinHeader_2x07_P2.54mm_Vertical
J3: Conn_01x03; PinHeader_1x03_P2.54mm_Vertical; Part Description 3pin 0.1" connector; not fitted
J7: Micro_SD_Card_Det; SDCARD_MOLEX_503398-1892; Part Description 9 (8 + 1) Position Card Connector micro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
J8: THD-20-R; PinHeader_2x20_P2.54mm_Vertical; Part Description PinHeader_2x20_P2.54mm_Vertical
J9: THD-02-R; PinHeader_2x02_P2.54mm_Vertical; Part Description PinHeader_2x02_P2.54mm_Vertical
J14: JST_SHBM04B-SRSS-TB; JST_SH_BM04B-SRSS-TB_1x04-1MP_P1.00mm_Vertical; Part Description 4 pin vertical 1mm pitch connector
Module1: ComputeModule5-CM5; Raspberry-Pi-5-Compute-Module; Part Description 100 Position Connector Receptacle, Cent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
R1, R10: 1k; R_0402_1005Metric; Part Description Resistor 1K M1005 1% 63mW
R2, R3: 470R; R_0402_1005Metric; Part Description Resistor 470R M1005 1% 63mW
R4: nf; R_0805_2012Metric_Pad1.20x1.40mm_HandSolder; not fitted
R5: 0R; R_0805_2012Metric_Pad1.20x1.40mm_HandSolder; Part Description Resistor 0R M2012 5%
SW1: Right angle Tact button; SW_Tactile_SPST_Angled_PTS645Vx58-2LFS; Part Description Right angle through hole Tact switch
TP3, TP5: TestPoint; TestPoint_Pad_2.0x2.0mm; Part Description Test point; not fitted
U1, U2: TPD4EUSB30; USON-10_2.5x1.0mm_P0.5mm; Part Description Quad TVS diode for high speed signals (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
U3: MagJack-A70-112-331N126; TRJG0926HENL; Part Description Gigabit Ethernet Magjack
U5: 74LVC1G07SE-7; SOT-353_SC-70-5; Part Description Buffer, Non-Inverting 1 Element 1 Bit p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
U18: RT9742GGJ5; SOT-23-5; Part Description Power Switch/Driver 1:1 N-Channel 1A TS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

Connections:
/+3.3v: D1.2 (A), D2.2 (A), J8.1, J8.17, Module1.84 (+3.3v_(Output)), Module1.86 (+3.3v_(Output)), R5.1, U3.15 (LEDY_A), U3.17 (LEDG_A), U5.5 (VCC), U18.5 (IN); also elsewhere on the board
/+5v: J8.2, J8.4, J14.1, Module1.77 (+5v_(Input)), Module1.79 (+5v_(Input)), Module1.81 (+5v_(Input)), Module1.83 (+5v_(Input)), Module1.85 (+5v_(Input)), Module1.87 (+5v_(Input)); also elsewhere on the board
/CC1: Module1.94 (CC1); also elsewhere on the board
/CC2: Module1.96 (CC2); also elsewhere on the board
/CM5_GPIO ( Ethernet, GPIO, SDCARD)/+1.8v: Module1.88 (+1.8v_(Output)), Module1.90 (+1.8v_(Output)), R4.1
/CM5_GPIO ( Ethernet, GPIO, SDCARD)/BT_nDis: J3.3, Module1.91 (BT_nDisable)
/CM5_GPIO ( Ethernet, GPIO, SDCARD)/CAM_GPIO0: Module1.97 (CAM_GPIO0); also elsewhere on the board
/CM5_GPIO ( Ethernet, GPIO, SDCARD)/CAM_GPIO1: Module1.100 (CAM_GPIO1); also elsewhere on the board
/CM5_GPIO ( Ethernet, GPIO, SDCARD)/EEPROM_nWP: J2.4, Module1.20 (EEPROM_nWP)
/CM5_GPIO ( Ethernet, GPIO, SDCARD)/ETH_LEDG: Module1.17 (Ethernet_nLED2(3.3v)), R2.2
/CM5_GPIO ( Ethernet, GPIO, SDCARD)/ETH_LEDY: Module1.15 (Ethernet_nLED3(3.3v)), R3.2
/CM5_GPIO ( Ethernet, GPIO, SDCARD)/GPIO2: J8.3, Module1.58 (GPIO2)
/CM5_GPIO ( Ethernet, GPIO, SDCARD)/GPIO3: J8.5, Module1.56 (GPIO3)
/CM5_GPIO ( Ethernet, GPIO, SDCARD)/GPIO4: J8.7, Module1.54 (GPIO4)
/CM5_GPIO ( Ethernet, GPIO, SDCARD)/GPIO5: J8.29, Module1.34 (GPIO5)
/CM5_GPIO ( Ethernet, GPIO, SDCARD)/GPIO6: J8.31, Module1.30 (GPIO6)
/CM5_GPIO ( Ethernet, GPIO, SDCARD)/GPIO7: J8.26, Module1.37 (GPIO7)
/CM5_GPIO ( Ethernet, GPIO, SDCARD)/GPIO8: J8.24, Module1.39 (GPIO8)
/CM5_GPIO ( Ethernet, GPIO, SDCARD)/GPIO9: J8.21, Module1.40 (GPIO9)
/CM5_GPIO ( Ethernet, GPIO, SDCARD)/GPIO10: J8.19, Module1.44 (GPIO10)
/CM5_GPIO ( Ethernet, GPIO, SDCARD)/GPIO11: J8.23, Module1.38 (GPIO11)
/CM5_GPIO ( Ethernet, GPIO, SDCARD)/GPIO12: J8.32, Module1.31 (GPIO12)
/CM5_GPIO ( Ethernet, GPIO, SDCARD)/GPIO13: J8.33, Module1.28 (GPIO13)
/CM5_GPIO ( Ethernet, GPIO, SDCARD)/GPIO14: J8.8, Module1.55 (GPIO14)
/CM5_GPIO ( Ethernet, GPIO, SDCARD)/GPIO15: J8.10, Module1.51 (GPIO15)
/CM5_GPIO ( Ethernet, GPIO, SDCARD)/GPIO16: J8.36, Module1.29 (GPIO16)
/CM5_GPIO ( Ethernet, GPIO, SDCARD)/GPIO17: J8.11, Module1.50 (GPIO17)
/CM5_GPIO ( Ethernet, GPIO, SDCARD)/GPIO18: J8.12, Module1.49 (GPIO18)
/CM5_GPIO ( Ethernet, GPIO, SDCARD)/GPIO19: J8.35, Module1.26 (GPIO19)
/CM5_GPIO ( Ethernet, GPIO, SDCARD)/GPIO20: J8.38, Module1.27 (GPIO20)
/CM5_GPIO ( Ethernet, GPIO, SDCARD)/GPIO21: J8.40, Module1.25 (GPIO21)
/CM5_GPIO ( Ethernet, GPIO, SDCARD)/GPIO22: J8.15, Module1.46 (GPIO22)
/CM5_GPIO ( Ethernet, GPIO, SDCARD)/GPIO23: J8.16, Module1.47 (GPIO23)
/CM5_GPIO ( Ethernet, GPIO, SDCARD)/GPIO24: J8.18, Module1.45 (GPIO24)
/CM5_GPIO ( Ethernet, GPIO, SDCARD)/GPIO25: J8.22, Module1.41 (GPIO25)
/CM5_GPIO ( Ethernet, GPIO, SDCARD)/GPIO26: J8.37, Module1.24 (GPIO26)
/CM5_GPIO ( Ethernet, GPIO, SDCARD)/GPIO27: J8.13, Module1.48 (GPIO27)
/CM5_GPIO ( Ethernet, GPIO, SDCARD)/GPIO_VREF: Module1.78 (GPIO_VREF(1.8v/3.3v_Input)), R4.2, R5.2; also elsewhere on the board
/CM5_GPIO ( Ethernet, GPIO, SDCARD)/ID_SC: J8.28, Module1.35 (ID_SC); also elsewhere on the board
/CM5_GPIO ( Ethernet, GPIO, SDCARD)/ID_SD: J8.27, Module1.36 (ID_SD); also elsewhere on the board
/CM5_GPIO ( Ethernet, GPIO, SDCARD)/PMIC_ENABLE: J2.12, Module1.99 (PMIC_ENABLE)
/CM5_GPIO ( Ethernet, GPIO, SDCARD)/PWM: J14.2, Module1.19 (FAN_PWM)
/CM5_GPIO ( Ethernet, GPIO, SDCARD)/PWR_BUT: J2.14, Module1.92 (PWR_BUT), SW1.1
/CM5_GPIO ( Ethernet, GPIO, SDCARD)/SD_CLK: J7.5 (CLK), Module1.57 (SD_CLK)
/CM5_GPIO ( Ethernet, GPIO, SDCARD)/SD_CMD: J7.3 (CMD), Module1.62 (SD_CMD)
/CM5_GPIO ( Ethernet, GPIO, SDCARD)/SD_DAT0: J7.7 (DAT0), Module1.63 (SD_DAT0)
/CM5_GPIO ( Ethernet, GPIO, SDCARD)/SD_DAT1: J7.8 (DAT1), Module1.67 (SD_DAT1)
/CM5_GPIO ( Ethernet, GPIO, SDCARD)/SD_DAT2: J7.1 (DAT2), Module1.69 (SD_DAT2)
/CM5_GPIO ( Ethernet, GPIO, SDCARD)/SD_DAT3: J7.2 (DAT3/CD), Module1.61 (SD_DAT3)
/CM5_GPIO ( Ethernet, GPIO, SDCARD)/SD_PWR: C5.1, J7.4 (VDD), U18.1 (OUT)
/CM5_GPIO ( Ethernet, GPIO, SDCARD)/SD_PWR_ON: Module1.75 (SD_PWR_ON), U18.4 (EN)
/CM5_GPIO ( Ethernet, GPIO, SDCARD)/SYNC_OUT: J2.6, Module1.18 (Ethernet_SYNC_OUT(1.8v))
/CM5_GPIO ( Ethernet, GPIO, SDCARD)/TACHO: J14.4, Module1.16 (FAN_TACHO)
/CM5_GPIO ( Ethernet, GPIO, SDCARD)/TR0_TAP: J9.3, U3.11 (VC1)
/CM5_GPIO ( Ethernet, GPIO, SDCARD)/TR1_TAP: J9.1, U3.12 (VC2)
/CM5_GPIO ( Ethernet, GPIO, SDCARD)/TR2_TAP: J9.2, U3.13 (VC3)
/CM5_GPIO ( Ethernet, GPIO, SDCARD)/TR3_TAP: J9.4, U3.14 (VC4)
/CM5_GPIO ( Ethernet, GPIO, SDCARD)/TRD0_N: Module1.10 (Ethernet_Pair0_N), U2.4 (D2+), U2.7, U3.2 (TRD0-)
/CM5_GPIO ( Ethernet, GPIO, SDCARD)/TRD0_P: Module1.12 (Ethernet_Pair0_P), U2.5 (D2-), U2.6, U3.1 (TRD0+)
/CM5_GPIO ( Ethernet, GPIO, SDCARD)/TRD1_N: Module1.6 (Ethernet_Pair1_N), U2.2 (D1-), U2.9, U3.6 (TRD1-)
/CM5_GPIO ( Ethernet, GPIO, SDCARD)/TRD1_P: Module1.4 (Ethernet_Pair1_P), U2.1 (D1+), U2.10, U3.3 (TRD1+)
/CM5_GPIO ( Ethernet, GPIO, SDCARD)/TRD2_N: Module1.9 (Ethernet_Pair2_N), U1.4 (D2+), U1.7, U3.8 (TRD2-)
/CM5_GPIO ( Ethernet, GPIO, SDCARD)/TRD2_P: Module1.11 (Ethernet_Pair2_P), U1.5 (D2-), U1.6, U3.7 (TRD2+)
/CM5_GPIO ( Ethernet, GPIO, SDCARD)/TRD3_N: Module1.5 (Ethernet_Pair3_N), U1.2 (D1-), U1.9, U3.10 (TRD3-)
/CM5_GPIO ( Ethernet, GPIO, SDCARD)/TRD3_P: Module1.3 (Ethernet_Pair3_P), U1.1 (D1+), U1.10, U3.9 (TRD3+)
/CM5_GPIO ( Ethernet, GPIO, SDCARD)/USBOTG: J2.10; also elsewhere on the board
/CM5_GPIO ( Ethernet, GPIO, SDCARD)/VBAT: BT1.1 (+), Module1.76 (VBAT)
/CM5_GPIO ( Ethernet, GPIO, SDCARD)/WL_nDis: J3.1, Module1.89 (WiFi_nDisable)
/CM5_GPIO ( Ethernet, GPIO, SDCARD)/nPWR_LED: Module1.95 (LED_nPWR), U5.2
/CM5_GPIO ( Ethernet, GPIO, SDCARD)/nRPIBOOT: J2.2, Module1.93 (nRPIBOOT)
/CM5_HighSpeed/SCL0: Module1.80 (SCL0); also elsewhere on the board
/CM5_HighSpeed/SDA0: Module1.82 (SDA0); also elsewhere on the board
GND: BT1.2 (-), C1.2, C5.2, J2.1, J2.3, J2.5, J2.7, J2.9, J2.11, J2.13, J3.2, J7.6 (VSS), J7.11 (SHIELD), J8.6, J8.9, J8.14, J8.20, J8.25, J8.30, J8.34, J8.39, J14.3, Module1.1 (GND), Module1.2 (GND), Module1.7 (GND), Module1.8 (GND), Module1.13 (GND), Module1.14 (GND), Module1.22 (GND), Module1.23 (GND), Module1.32 (GND), Module1.33 (GND), Module1.42 (GND), Module1.43 (GND), Module1.52 (GND), Module1.53 (GND), Module1.59 (GND), Module1.60 (GND), Module1.65 (GND), Module1.66 (GND), Module1.71 (GND), Module1.74 (GND), Module1.98 (GND), SW1.2, U1.3 (GND), U1.8 (GND), U2.3 (GND), U2.8 (GND), U3.19 (SHIELD), U3.20 (SHIELD), U5.3 (GND), U18.2 (GND); also elsewhere on the board
unnamed: C1.1, U3.4 (CT), U3.5 (CT)
unnamed: D1.1 (K), R10.1, TP5.1
unnamed: D2.1 (K), R1.1, TP3.1
unnamed: Module1.21 (LED_nACT), R1.2
unnamed: R10.2, U5.4
unnamed: R3.1, U3.18 (LEDG_K)
unnamed: R2.1, U3.16 (LEDY_K)

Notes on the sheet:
40Way GPIO Header
Activity LED
FAN connector
Ethernet POE Protection
GPIO Voltage select
Not Fitted header
POE Header
Force RPIBOOT = Jumper Pins 1-2
PWR LED
Ethernet
CM5Lite SDCARD I/F

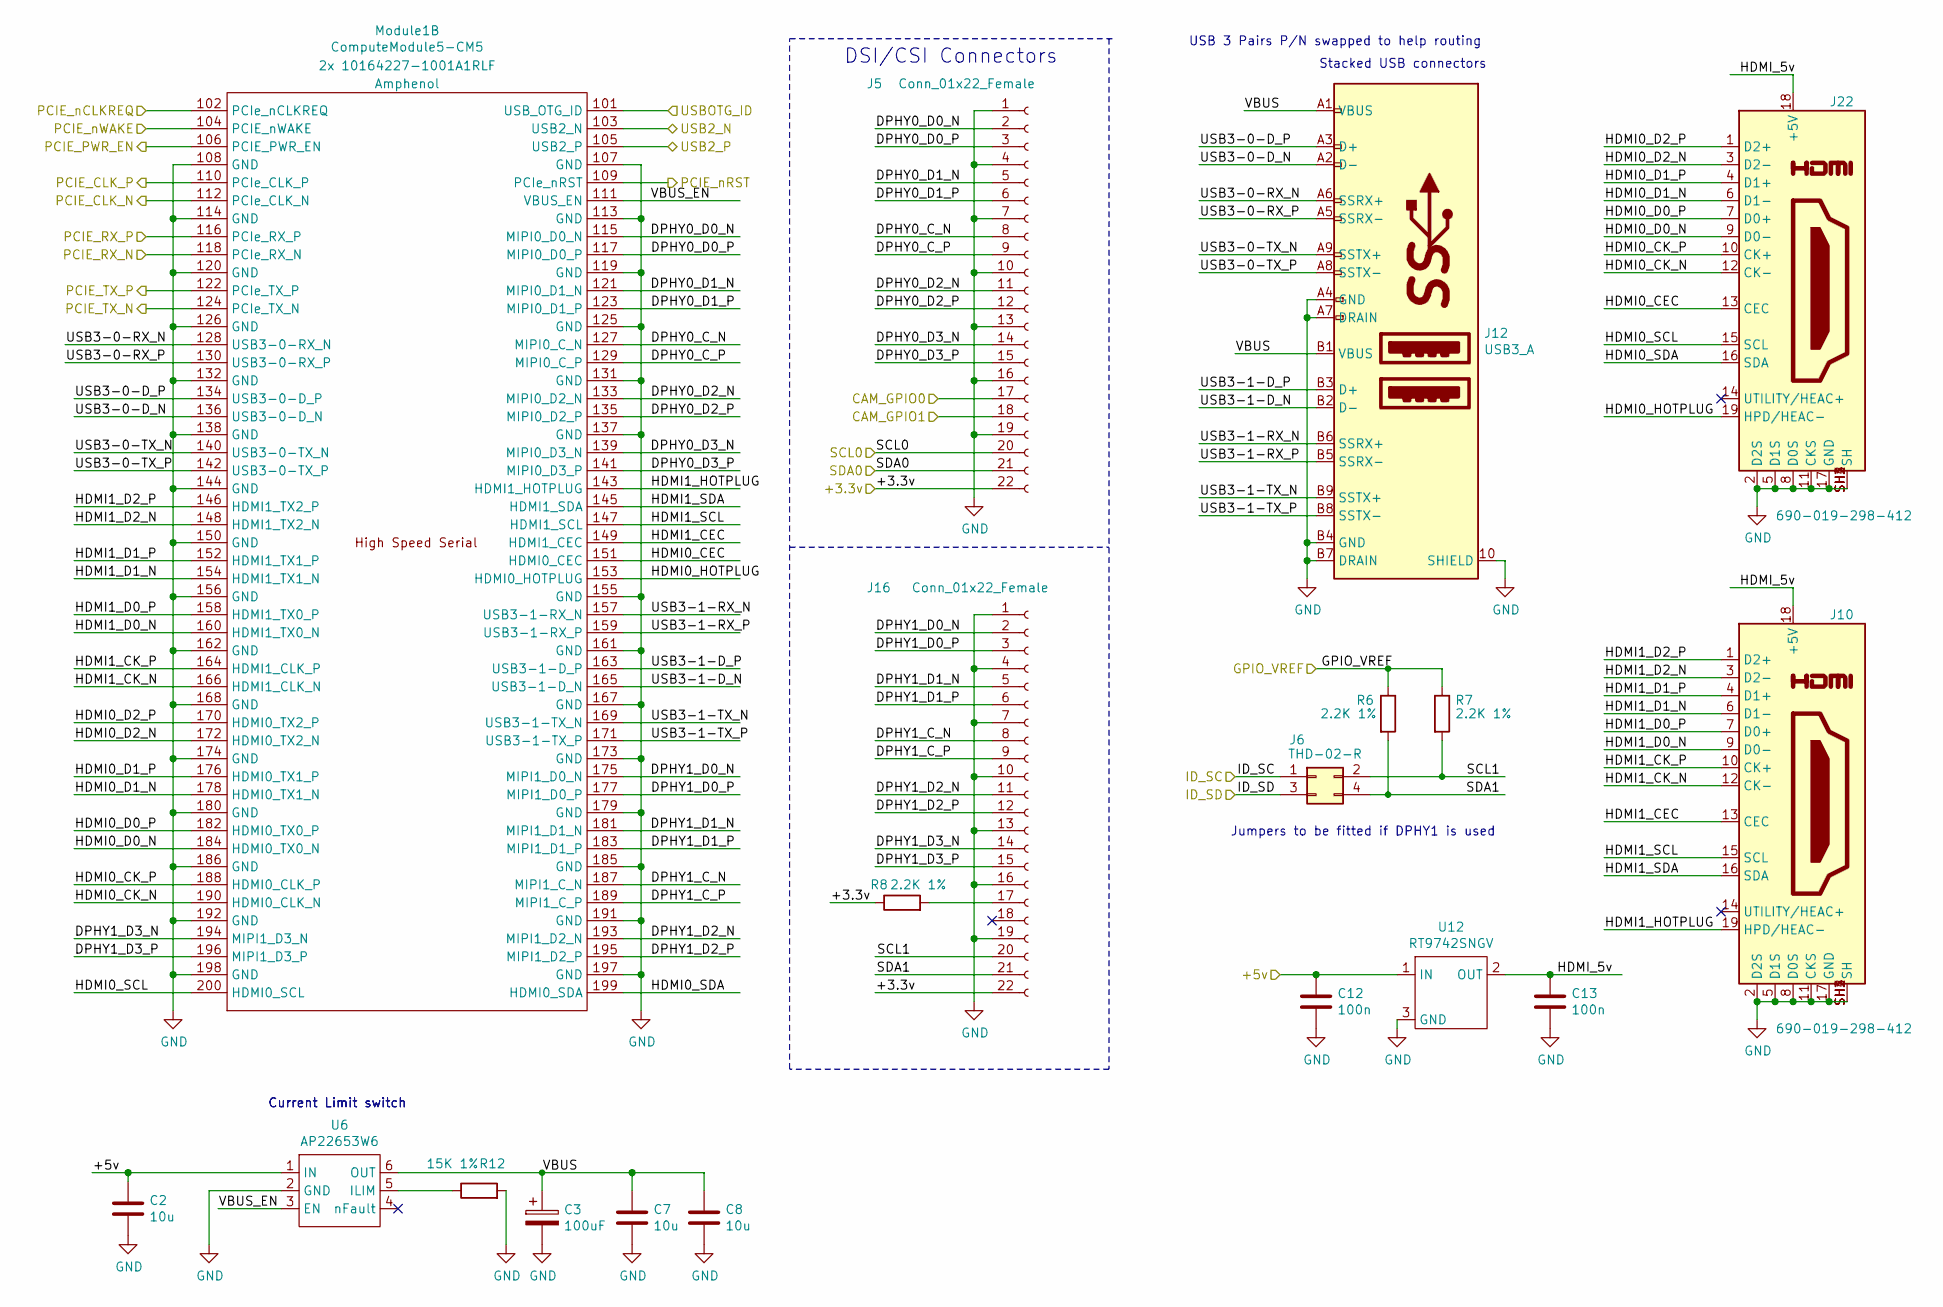
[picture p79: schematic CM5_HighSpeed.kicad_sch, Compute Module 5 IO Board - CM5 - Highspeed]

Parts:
C2, C7, C8: 10u; C_0805_2012Metric; Part Description 10uF 10% 10V Ceramic Capacitor X7R 0805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
C3: 100uF; CP_EIA-7343-31_Kemet-D; Part Description Capacitor, SP-Cap, 100u, 6.3V, 15mR ESR
C12, C13: 100n; C_0402_1005Metric; Part Description 0.1uF 10% 16V Ceramic Capacitor X7R 040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
J5, J16: Conn_01x22_Female; Hirose_FH12-22S-0.5SH_1x22-1MP_P0.50mm_Horizontal; Part Description 22 Position FFC, FPC Connector Contacts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
J6: THD-02-R; PinHeader_2x02_P2.54mm_Vertical; Part Description PinHeader_2x02_P2.54mm_Vertical
J10, J22: 690-019-298-412; EDAC 690-019-298-412; Part Description HDMI Connector, Right Angle, 19 Contact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
J12: USB3_A; MTCONN_UBAF30-D2011; Part Description Dual USB 3 connector
Module1: ComputeModule5-CM5; Raspberry-Pi-5-Compute-Module; Part Description 100 Position Connector Receptacle, Cent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
R6, R7, R8: 2.2K 1%; R_0402_1005Metric; Part Description Resistor 2.2K M1005 1% 63mW
R12: 15K 1%; R_0402_1005Metric; Part Description Resistor 15K M1005 1% 63mW
U6: AP22653W6; SOT-23-6; Part Description Power Switch/Driver 1:1 P-Channel 2.1A 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
U12: RT9742SNGV; TSOT-23_HandSoldering; Part Description Power Switch/Driver 1:1 N-Channel 500mA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

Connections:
/+3.3v: J5.22, J16.22, R8.1; also elsewhere on the board
/+5v: C2.1, C12.1, U6.1 (IN), U12.1 (IN); also elsewhere on the board
/CM5_GPIO ( Ethernet, GPIO, SDCARD)/CAM_GPIO0: J5.17; also elsewhere on the board
/CM5_GPIO ( Ethernet, GPIO, SDCARD)/CAM_GPIO1: J5.18; also elsewhere on the board
/CM5_GPIO ( Ethernet, GPIO, SDCARD)/GPIO_VREF: R6.1, R7.1; also elsewhere on the board
/CM5_GPIO ( Ethernet, GPIO, SDCARD)/ID_SC: J6.1; also elsewhere on the board
/CM5_GPIO ( Ethernet, GPIO, SDCARD)/ID_SD: J6.3; also elsewhere on the board
/CM5_GPIO ( Ethernet, GPIO, SDCARD)/USBOTG: Module1.101 (USB_OTG_ID); also elsewhere on the board
/CM5_HighSpeed/DPHY0_C_N: J5.8, Module1.127 (DPHY0_C_N)
/CM5_HighSpeed/DPHY0_C_P: J5.9, Module1.129 (DPHY0_C_P)
/CM5_HighSpeed/DPHY0_D0_N: J5.2, Module1.115 (DPHY0_D0_N)
/CM5_HighSpeed/DPHY0_D0_P: J5.3, Module1.117 (DPHY0_D0_P)
/CM5_HighSpeed/DPHY0_D1_N: J5.5, Module1.121 (DPHY0_D1_N)
/CM5_HighSpeed/DPHY0_D1_P: J5.6, Module1.123 (DPHY0_D1_P)
/CM5_HighSpeed/DPHY0_D2_N: J5.11, Module1.133 (DPHY0_D2_N)
/CM5_HighSpeed/DPHY0_D2_P: J5.12, Module1.135 (DPHY0_D2_P)
/CM5_HighSpeed/DPHY0_D3_N: J5.14, Module1.139 (DPHY0_D3_N)
/CM5_HighSpeed/DPHY0_D3_P: J5.15, Module1.141 (DPHY0_D3_P)
/CM5_HighSpeed/DPHY1_C_N: J16.8, Module1.187 (DPHY1_C_N)
/CM5_HighSpeed/DPHY1_C_P: J16.9, Module1.189 (DPHY1_C_P)
/CM5_HighSpeed/DPHY1_D0_N: J16.2, Module1.175 (DPHY1_D0_N)
/CM5_HighSpeed/DPHY1_D0_P: J16.3, Module1.177 (DPHY1_D0_P)
/CM5_HighSpeed/DPHY1_D1_N: J16.5, Module1.181 (DPHY1_D1_N)
/CM5_HighSpeed/DPHY1_D1_P: J16.6, Module1.183 (DPHY1_D1_P)
/CM5_HighSpeed/DPHY1_D2_N: J16.11, Module1.193 (DPHY1_D2_N)
/CM5_HighSpeed/DPHY1_D2_P: J16.12, Module1.195 (DPHY1_D2_P)
/CM5_HighSpeed/DPHY1_D3_N: J16.14, Module1.194 (DPHY1_D3_N)
/CM5_HighSpeed/DPHY1_D3_P: J16.15, Module1.196 (DPHY1_D3_P)
/CM5_HighSpeed/HDMI0_CEC: J22.13 (CEC), Module1.151 (HDMI0_CEC)
/CM5_HighSpeed/HDMI0_CK_N: J22.12 (CK-), Module1.190 (HDMI0_CLK_N)
/CM5_HighSpeed/HDMI0_CK_P: J22.10 (CK+), Module1.188 (HDMI0_CLK_P)
/CM5_HighSpeed/HDMI0_D0_N: J22.9 (D0-), Module1.184 (HDMI0_TX0_N)
/CM5_HighSpeed/HDMI0_D0_P: J22.7 (D0+), Module1.182 (HDMI0_TX0_P)
/CM5_HighSpeed/HDMI0_D1_N: J22.6 (D1-), Module1.178 (HDMI0_TX1_N)
/CM5_HighSpeed/HDMI0_D1_P: J22.4 (D1+), Module1.176 (HDMI0_TX1_P)
/CM5_HighSpeed/HDMI0_D2_N: J22.3 (D2-), Module1.172 (HDMI0_TX2_N)
/CM5_HighSpeed/HDMI0_D2_P: J22.1 (D2+), Module1.170 (HDMI0_TX2_P)
/CM5_HighSpeed/HDMI0_HOTPLUG: J22.19 (HPD/HEAC-), Module1.153 (HDMI0_HOTPLUG)
/CM5_HighSpeed/HDMI0_SCL: J22.15 (SCL), Module1.200 (HDMI0_SCL)
/CM5_HighSpeed/HDMI0_SDA: J22.16 (SDA), Module1.199 (HDMI0_SDA)
/CM5_HighSpeed/HDMI1_CEC: J10.13 (CEC), Module1.149 (HDMI1_CEC)
/CM5_HighSpeed/HDMI1_CK_N: J10.12 (CK-), Module1.166 (HDMI1_CLK_N)
/CM5_HighSpeed/HDMI1_CK_P: J10.10 (CK+), Module1.164 (HDMI1_CLK_P)
/CM5_HighSpeed/HDMI1_D0_N: J10.9 (D0-), Module1.160 (HDMI1_TX0_N)
/CM5_HighSpeed/HDMI1_D0_P: J10.7 (D0+), Module1.158 (HDMI1_TX0_P)
/CM5_HighSpeed/HDMI1_D1_N: J10.6 (D1-), Module1.154 (HDMI1_TX1_N)
/CM5_HighSpeed/HDMI1_D1_P: J10.4 (D1+), Module1.152 (HDMI1_TX1_P)
/CM5_HighSpeed/HDMI1_D2_N: J10.3 (D2-), Module1.148 (HDMI1_TX2_N)
/CM5_HighSpeed/HDMI1_D2_P: J10.1 (D2+), Module1.146 (HDMI1_TX2_P)
/CM5_HighSpeed/HDMI1_HOTPLUG: J10.19 (HPD/HEAC-), Module1.143 (HDMI1_HOTPLUG)
/CM5_HighSpeed/HDMI1_SCL: J10.15 (SCL), Module1.147 (HDMI1_SCL)
/CM5_HighSpeed/HDMI1_SDA: J10.16 (SDA), Module1.145 (HDMI1_SDA)
/CM5_HighSpeed/HDMI_5v: C13.1, J10.18 (+5V), J22.18 (+5V), U12.2 (OUT)
/CM5_HighSpeed/PCIE_CLK_N: Module1.112 (PCIe_CLK_N); also elsewhere on the board
/CM5_HighSpeed/PCIE_CLK_P: Module1.110 (PCIe_CLK_P); also elsewhere on the board
/CM5_HighSpeed/PCIE_PWR_EN: Module1.106 (PCIE_PWR_EN); also elsewhere on the board
/CM5_HighSpeed/PCIE_RX_N: Module1.118 (PCIe_RX_N); also elsewhere on the board
/CM5_HighSpeed/PCIE_RX_P: Module1.116 (PCIe_RX_P); also elsewhere on the board
/CM5_HighSpeed/PCIE_TX_N: Module1.124 (PCIe_TX_N); also elsewhere on the board
/CM5_HighSpeed/PCIE_TX_P: Module1.122 (PCIe_TX_P); also elsewhere on the board
/CM5_HighSpeed/PCIE_nCLKREQ: Module1.102 (PCIe_nCLKREQ); also elsewhere on the board
/CM5_HighSpeed/PCIE_nRST: Module1.109 (PCIe_nRST); also elsewhere on the board
/CM5_HighSpeed/PCIE_nWAKE: Module1.104 (PCIE_nWAKE); also elsewhere on the board
/CM5_HighSpeed/SCL0: J5.20; also elsewhere on the board
/CM5_HighSpeed/SCL1: J6.2, J16.20, R7.2
/CM5_HighSpeed/SDA0: J5.21; also elsewhere on the board
/CM5_HighSpeed/SDA1: J6.4, J16.21, R6.2
/CM5_HighSpeed/USB3-0-D_N: J12.A2 (D-), Module1.136 (USB3-0-D_N)
/CM5_HighSpeed/USB3-0-D_P: J12.A3 (D+), Module1.134 (USB3-0-D_P)
/CM5_HighSpeed/USB3-0-RX_N: J12.A6 (SSRX+), Module1.128 (USB3-0-RX_N)
/CM5_HighSpeed/USB3-0-RX_P: J12.A5 (SSRX-), Module1.130 (USB3-0-RX_P)
/CM5_HighSpeed/USB3-0-TX_N: J12.A9 (SSTX+), Module1.140 (USB3-0-TX_N)
/CM5_HighSpeed/USB3-0-TX_P: J12.A8 (SSTX-), Module1.142 (USB3-0-TX_P)
/CM5_HighSpeed/USB3-1-D_N: J12.B2 (D-), Module1.165 (USB3-1-D_N)
/CM5_HighSpeed/USB3-1-D_P: J12.B3 (D+), Module1.163 (USB3-1-D_P)
/CM5_HighSpeed/USB3-1-RX_N: J12.B6 (SSRX+), Module1.157 (USB3-1-RX_N)
/CM5_HighSpeed/USB3-1-RX_P: J12.B5 (SSRX-), Module1.159 (USB3-1-RX_P)
/CM5_HighSpeed/USB3-1-TX_N: J12.B9 (SSTX+), Module1.169 (USB3-1-TX_N)
/CM5_HighSpeed/USB3-1-TX_P: J12.B8 (SSTX-), Module1.171 (USB3-1-TX_P)
/CM5_HighSpeed/VBUS: C3.1, C7.1, C8.1, J12.A1 (VBUS), J12.B1 (VBUS), U6.6 (OUT)
/CM5_HighSpeed/VBUS_EN: Module1.111 (VBUS_EN), U6.3 (EN)
/USB2_N: Module1.103 (USB2_N); also elsewhere on the board
/USB2_P: Module1.105 (USB2_P); also elsewhere on the board
GND: C2.2, C3.2, C7.2, C8.2, C12.2, C13.2, J5.1, J5.4, J5.7, J5.10, J5.13, J5.16, J5.19, J10.2 (D2S), J10.5 (D1S), J10.8 (D0S), J10.11 (CKS), J10.17 (GND), J10.SH1 (SH), J10.SH2 (SH), J10.SH3 (SH), J10.SH4 (SH), J12.10 (SHIELD), J12.A4 (GND), J12.A7 (DRAIN), J12.B4 (GND), J12.B7 (DRAIN), J16.1, J16.4, J16.7, J16.10, J16.13, J16.16, J16.19, J22.2 (D2S), J22.5 (D1S), J22.8 (D0S), J22.11 (CKS), J22.17 (GND), J22.SH1 (SH), J22.SH2 (SH), J22.SH3 (SH), J22.SH4 (SH), Module1.107 (GND), Module1.108 (GND), Module1.113 (GND), Module1.114 (GND), Module1.119 (GND), Module1.120 (GND), Module1.125 (GND), Module1.126 (GND), Module1.131 (GND), Module1.132 (GND), Module1.137 (GND), Module1.138 (GND), Module1.144 (GND), Module1.150 (GND), Module1.155 (GND), Module1.156 (GND), Module1.161 (GND), Module1.162 (GND), Module1.167 (GND), Module1.168 (GND), Module1.173 (GND), Module1.174 (GND), Module1.179 (GND), Module1.180 (GND), Module1.185 (GND), Module1.186 (GND), Module1.191 (GND), Module1.192 (GND), Module1.197 (GND), Module1.198 (GND), R12.2, U6.2 (GND), U12.3 (GND); also elsewhere on the board
unnamed: J16.17, R8.2
unnamed: R12.1, U6.5 (ILIM)

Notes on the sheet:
USB 3 Pairs P/N swapped to help routing
Jumpers to be fitted if DPHY1 is used
Current Limit switch
DSI/CSI Connectors
Stacked USB connectors

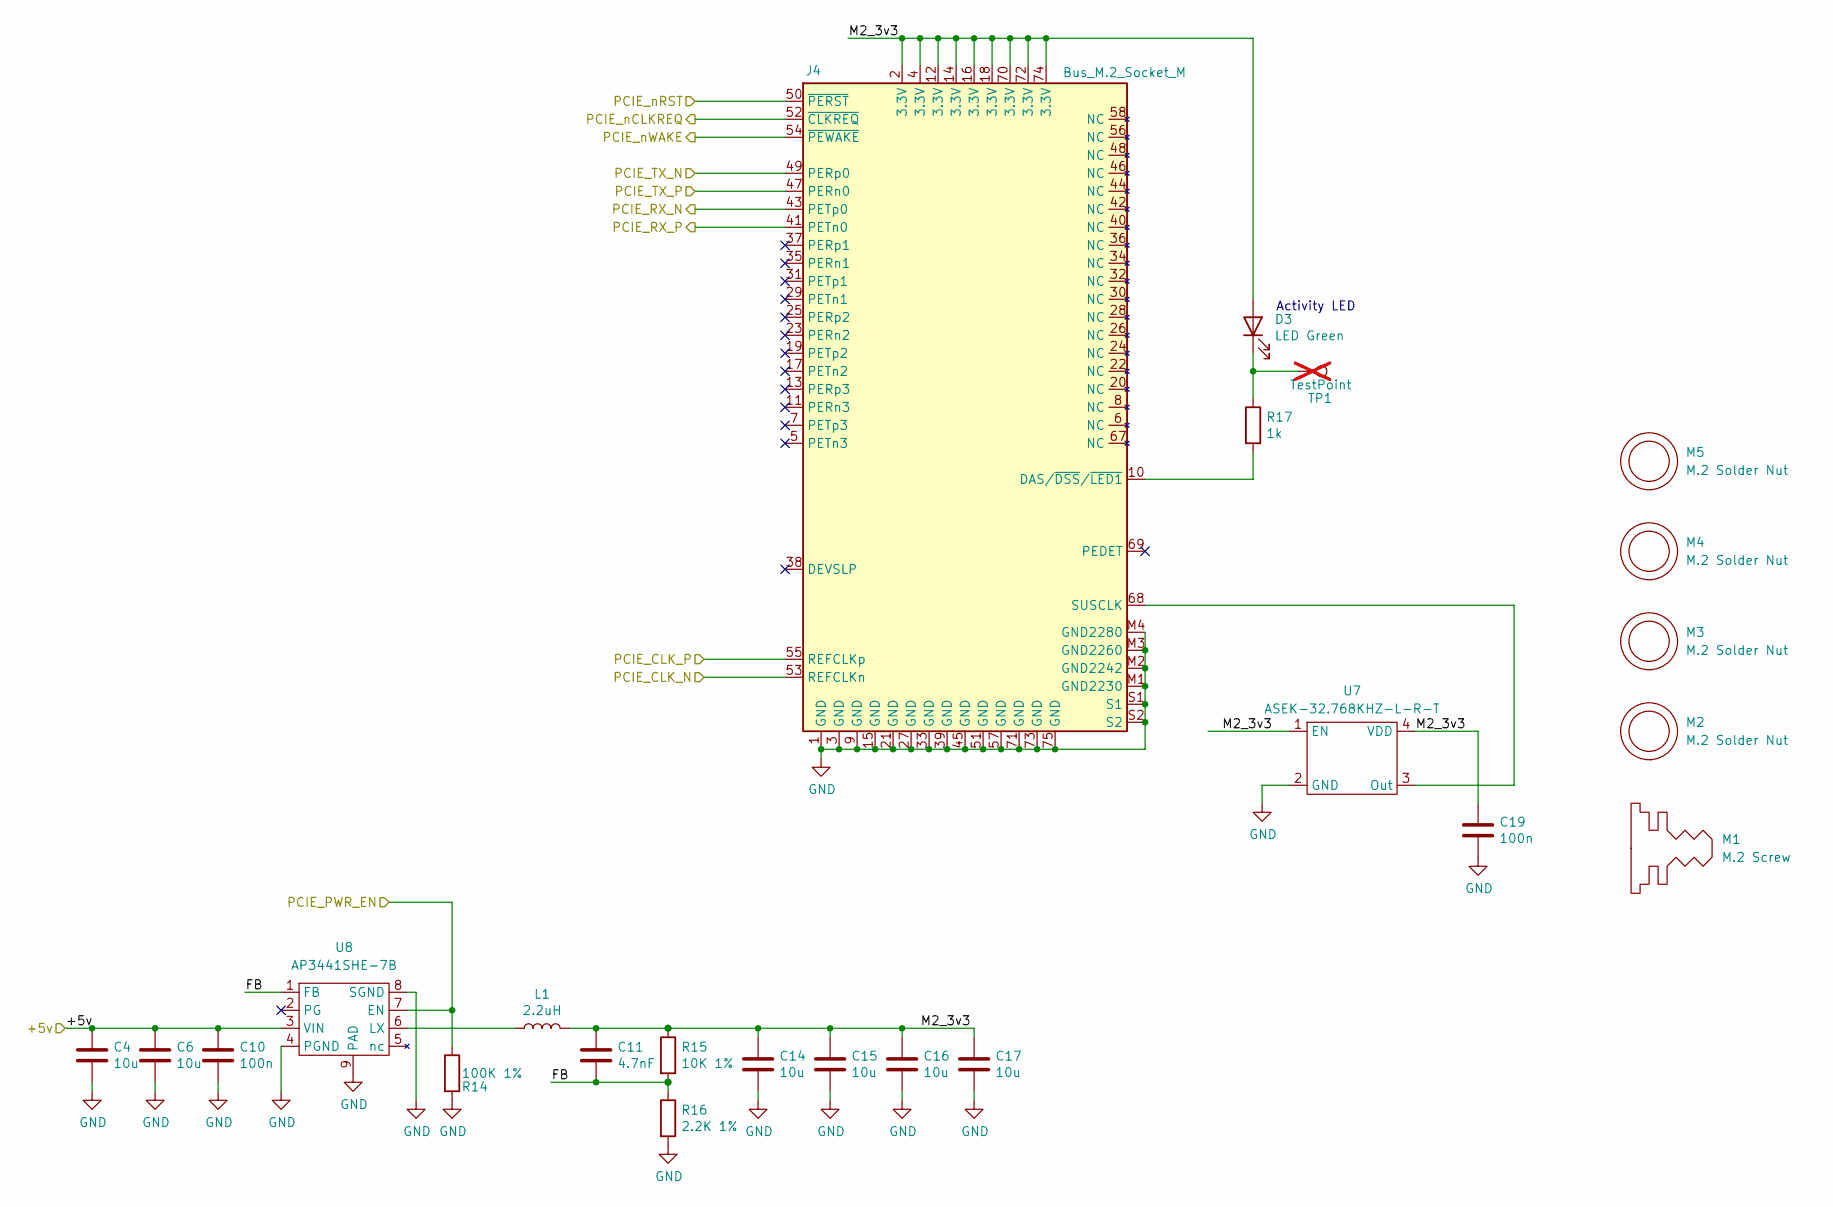
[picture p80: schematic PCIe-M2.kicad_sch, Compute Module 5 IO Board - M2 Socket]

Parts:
C4, C6, C14, C15, C16, C17: 10u; C_0805_2012Metric; Part Description 10uF 10% 10V Ceramic Capacitor X7R 0805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
C10, C19: 100n; C_0402_1005Metric; Part Description 0.1uF 10% 16V Ceramic Capacitor X7R 040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
C11: 4.7nF; C_0402_1005Metric; Part Description 4.7nF capacitor 0402
D3: LED Green; LED_0603_1608Metric; Part Description Green 572nm LED Indication - Discrete 2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
J4: Bus_M.2_Socket_M; M.2 M Key socket; Part Description M.2 M Key connector
L1: 2.2uH; L_Bourns_SRP5030CC; Part Description Inductor, SMT, 2520, 2u2, IRMS=7A, ISAT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
M1: M.2 Screw; Part Description M.2 Screw
M2, M3, M4, M5: M.2 Solder Nut; Part Description Solder nut for M.2 slot
R14: 100K 1%; R_0402_1005Metric; Part Description Resistor 100K M1005 1% 63mW
R15: 10K 1%; R_0402_1005Metric; Part Description Resistor 10K M1005 1% 63mW
R16: 2.2K 1%; R_0402_1005Metric; Part Description Resistor 2.2K M1005 1% 63mW
R17: 1k; R_0402_1005Metric; Part Description Resistor 1K M1005 1% 63mW
TP1: TestPoint; TestPoint_Pad_2.0x2.0mm; Part Description Test point; not fitted
U7: ASEK-32.768KHZ-L-R-T; Crystal_SMD_3225-4Pin_3.2x2.5mm; Part Description 32KHz Xtal oscilator
U8: AP3441SHE-7B; DFN-8-1EP_2x2mm_P0.5mm_EP1.05x1.75mm; Part Description 3A DC-DC converter

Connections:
/+5v: C4.1, C6.1, C10.1, U8.3 (VIN); also elsewhere on the board
/CM5_HighSpeed/PCIE_CLK_N: J4.53 (REFCLKn); also elsewhere on the board
/CM5_HighSpeed/PCIE_CLK_P: J4.55 (REFCLKp); also elsewhere on the board
/CM5_HighSpeed/PCIE_PWR_EN: R14.1, U8.7 (EN); also elsewhere on the board
/CM5_HighSpeed/PCIE_RX_N: J4.43 (PETp0); also elsewhere on the board
/CM5_HighSpeed/PCIE_RX_P: J4.41 (PETn0); also elsewhere on the board
/CM5_HighSpeed/PCIE_TX_N: J4.49 (PERp0); also elsewhere on the board
/CM5_HighSpeed/PCIE_TX_P: J4.47 (PERn0); also elsewhere on the board
/CM5_HighSpeed/PCIE_nCLKREQ: J4.52 (~CLKREQ); also elsewhere on the board
/CM5_HighSpeed/PCIE_nRST: J4.50 (~PERST); also elsewhere on the board
/CM5_HighSpeed/PCIE_nWAKE: J4.54 (~PEWAKE); also elsewhere on the board
/PCIe-M2/FB: C11.2, R15.2, R16.1, U8.1 (FB)
/PCIe-M2/M2_3v3: C11.1, C14.1, C15.1, C16.1, C17.1, C19.1, D3.2 (A), J4.2 (3.3V), J4.4 (3.3V), J4.12 (3.3V), J4.14 (3.3V), J4.16 (3.3V), J4.18 (3.3V), J4.70 (3.3V), J4.72 (3.3V), J4.74 (3.3V), L1.2, R15.1, U7.1 (EN), U7.4 (VDD)
GND: C4.2, C6.2, C10.2, C14.2, C15.2, C16.2, C17.2, C19.2, J4.1 (GND), J4.3 (GND), J4.9 (GND), J4.15 (GND), J4.21 (GND), J4.27 (GND), J4.33 (GND), J4.39 (GND), J4.45 (GND), J4.51 (GND), J4.57 (GND), J4.71 (GND), J4.73 (GND), J4.75 (GND), J4.M1 (GND2230), J4.M2 (GND2242), J4.M3 (GND2260), J4.M4 (GND2280), J4.S1, J4.S2, R14.2, R16.2, U7.2 (GND), U8.4 (PGND), U8.8 (SGND), U8.9 (PAD); also elsewhere on the board
unnamed: D3.1 (K), R17.1, TP1.1
unnamed: J4.10 (DAS/~DSS/~LED1), R17.2
unnamed: J4.68 (SUSCLK), U7.3 (Out)
unnamed: L1.1, U8.6 (LX)

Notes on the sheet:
Activity LED

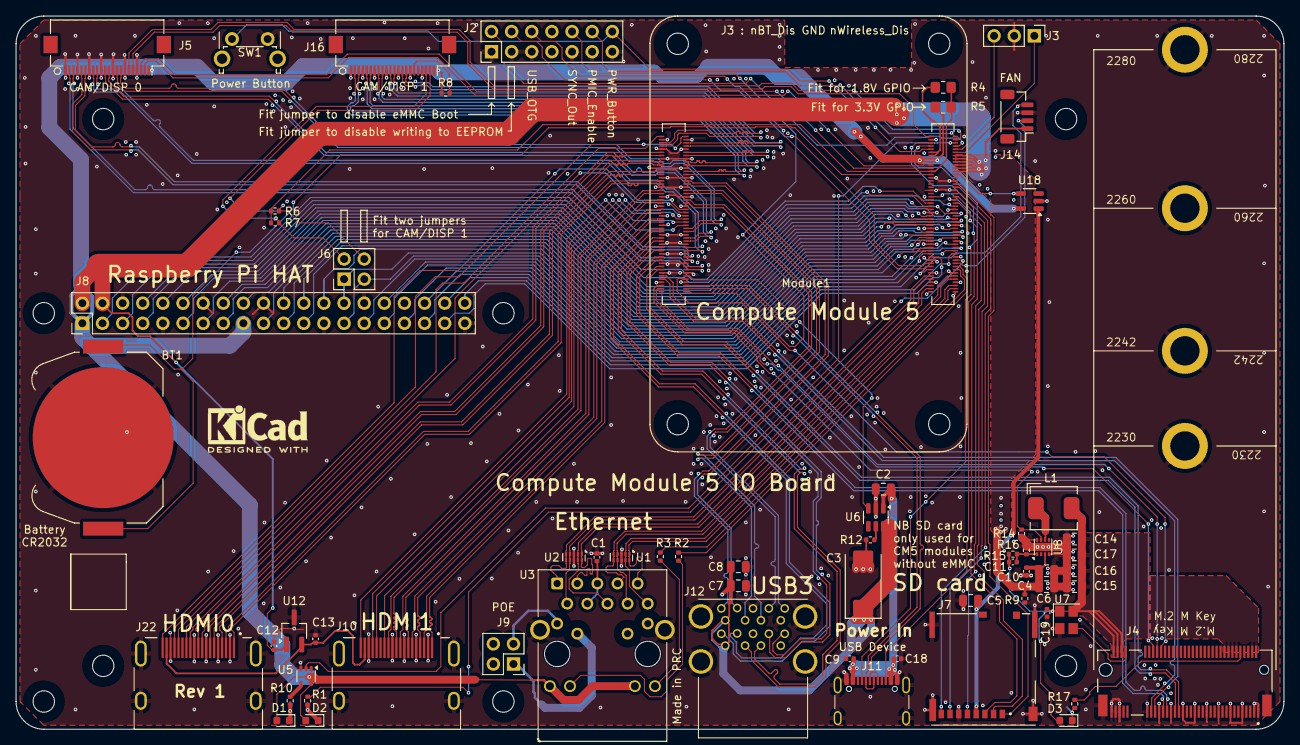
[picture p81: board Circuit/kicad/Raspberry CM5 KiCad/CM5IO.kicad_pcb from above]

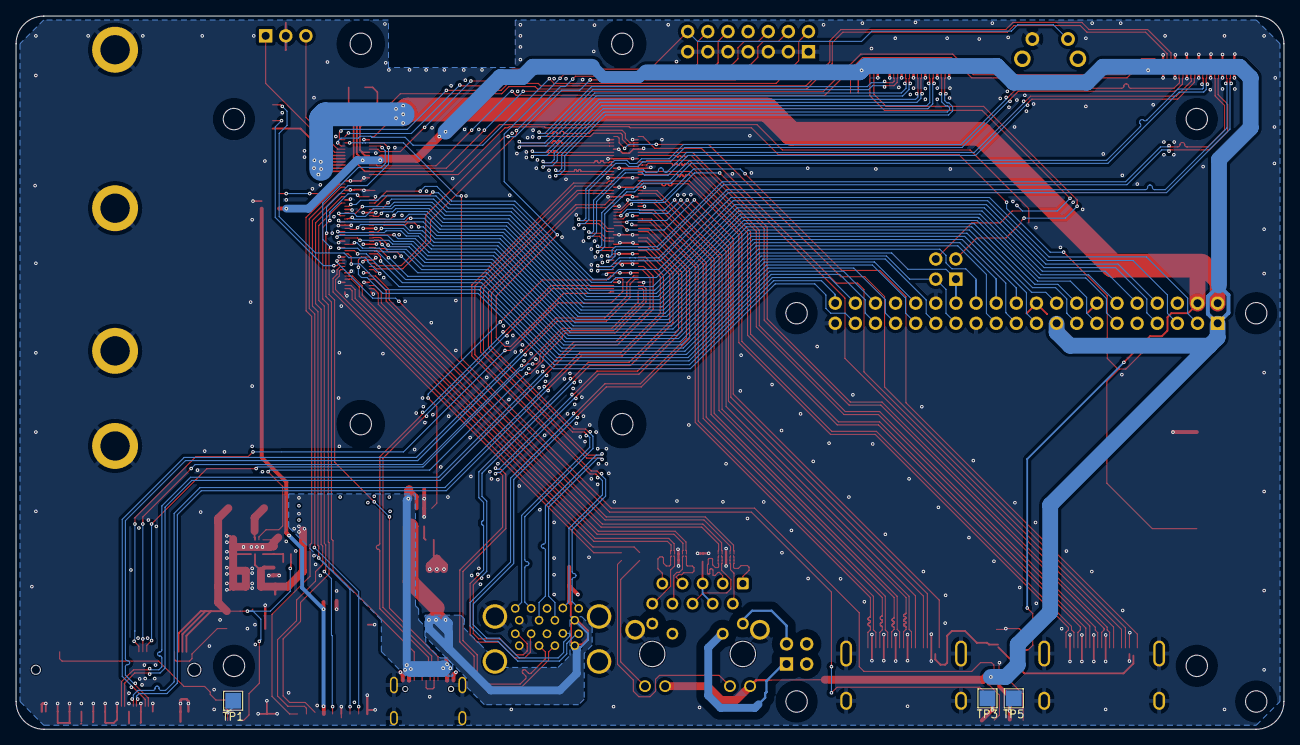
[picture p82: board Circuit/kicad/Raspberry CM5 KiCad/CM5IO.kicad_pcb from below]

Board: 4 copper layers, 160.0 x 90.0 mm, 76 parts (3 on the bottom side), 161 nets.

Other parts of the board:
logo1: KiCad-Logo2_5mm_SilkScreen

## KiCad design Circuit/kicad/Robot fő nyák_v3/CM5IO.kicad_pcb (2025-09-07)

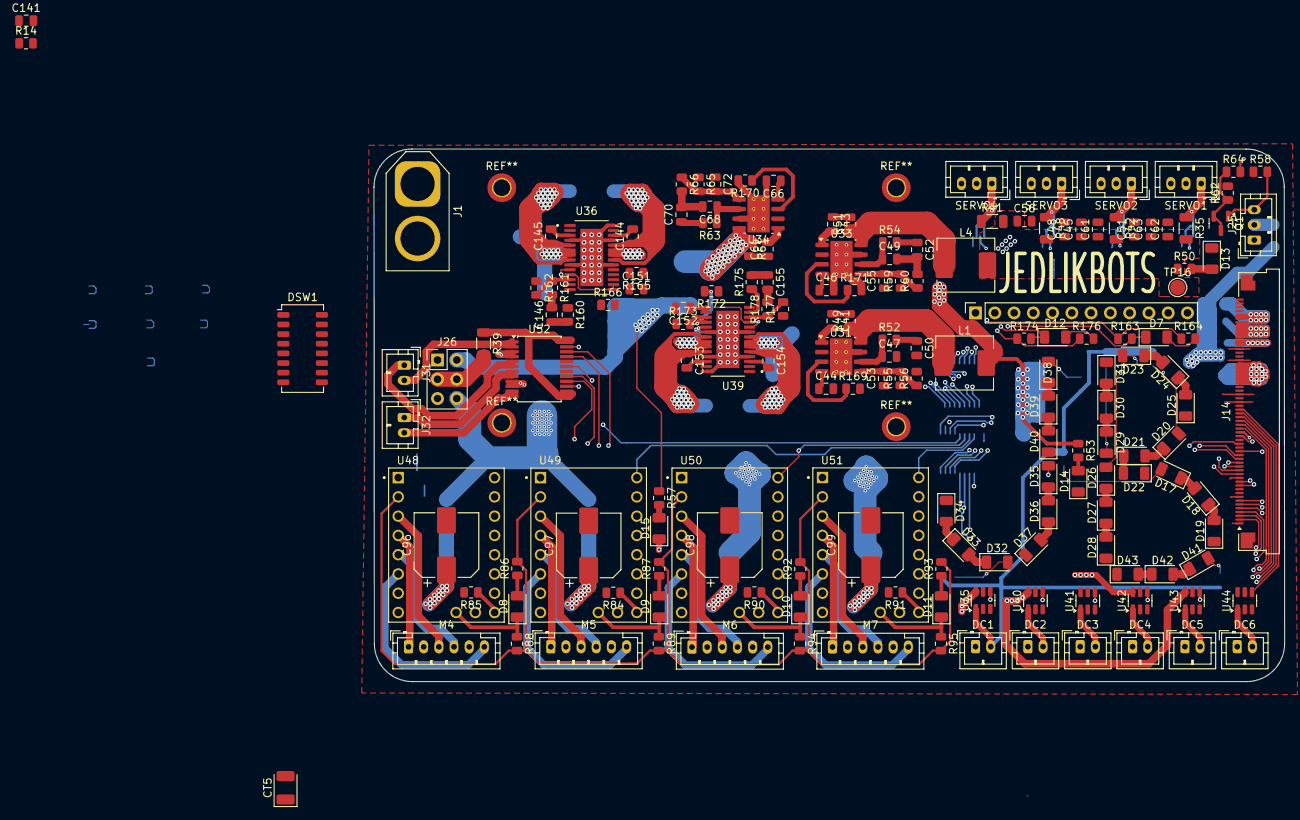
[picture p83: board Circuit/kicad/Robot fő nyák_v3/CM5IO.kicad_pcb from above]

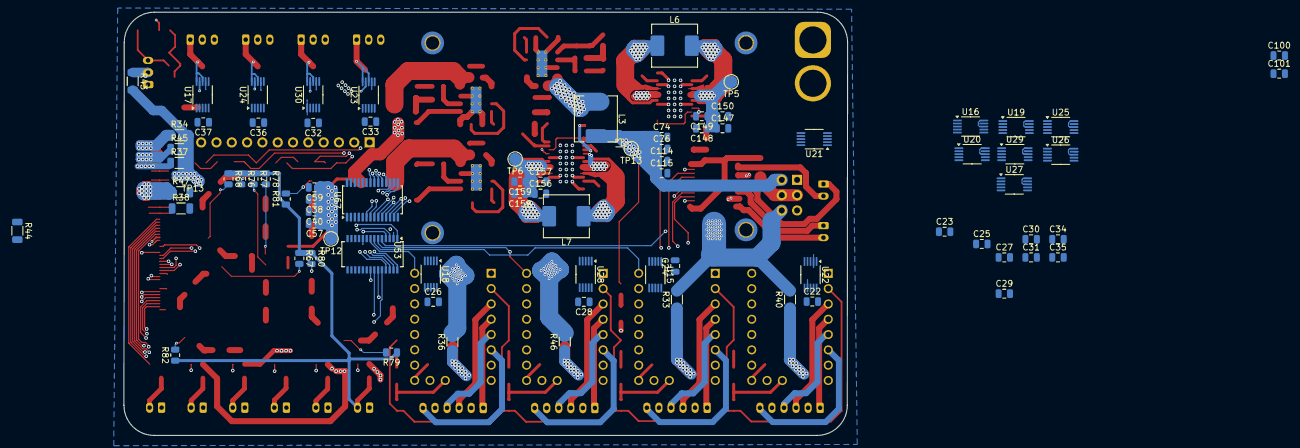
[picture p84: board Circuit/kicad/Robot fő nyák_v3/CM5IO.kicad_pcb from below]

Board: 6 copper layers, 120.0 x 70.2 mm, 246 parts (79 on the bottom side), 203 nets.

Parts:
C22, C23, C24, C25, C26, C27, C28, C29, C30, C31, C32, C33, C34, C35, C36, C37, C100, C101, C141: 1uf; C_0805_2012Metric
C38, C40, C45, C48, C51, C56, C57, C59, C61, C62, C63, C74, C76, C114, C115, C147, C148, C149, C150, C151, C152, C156, C157, C158, C159: 4,7uf; C_0805_2012Metric
C41, C43, C44, C46, C64, C66, C144, C145, C153, C154: 100n; C_0805_2012Metric
C47, C49, C53, C55, C68, C72: 68pf; C_0805_2012Metric
C50, C52, C70: 1.2nF; C_0805_2012Metric
C96, C97, C98, C99: 470uf; CP_Elec_8x10
C146, C155: 330pf; C_0805_2012Metric
CT5: 10uf; CP_EIA-3528-21_Kemet-B
D7, D8, D9, D10, D11, D12, D13, D14, D15, D17, D18, D19, D20, D21, D22, D23, D24, D25, D26, D27, D28, D29, D30, D31, D32, D33, D34, D35, D36, D37, D38, D39, D40, D41, D42, D43: LED; D_1206_3216Metric
DC1, DC2, DC3, DC4, DC5, DC6: Conn_01x02_Socket; JST_PH_B2B-PH-K_1x02_P2.00mm_Vertical
DSW1: SW_DIP_x08; SW_DIP_SPSTx08_Slide_Copal_CHS-08A_W5.08mm_P1.27mm_JPin
J1: XT60-M; AMASS_XT60-M_1x02_P7.20mm_Vertical
J14: Conn_01x60_MountingPin; Amphenol_F32Q-1A7x1-11060_1x60-1MP_P0.5mm_Horizontal
J16: Conn_01x12; PinSocket_1x12_P2.54mm_Vertical
J25: Conn_01x03_Pin; JST_PH_B3B-PH-K_1x03_P2.00mm_Vertical
J26: Conn_02x03_Counter_Clockwise; PinHeader_2x03_P2.54mm_Vertical
J31, J32: Conn_01x02_Pin; JST_PH_B2B-PH-K_1x02_P2.00mm_Vertical
L1, L3, L4, L6, L7: HCM0703-3R3-R; L_KOHERelec_MDA7030
M4, M5, M6, M7: Stepper_Motor_unipolar_6pin; JST_PH_B6B-PH-K_1x06_P2.00mm_Vertical
Q1: bss138; SOT-23
R14, R84, R85, R88, R89, R90, R91, R94, R95, R163, R174: 10k; R_0805_2012Metric
R33, R34, R35, R36, R37, R38, R39, R40, R41, R42, R43, R44, R45, R46, R47, R48: 0.025Ω; R_1206_3216Metric
R49, R51, R61: 10R; R_0805_2012Metric
R50: 1k; R_0805_2012Metric
R52, R54, R63: 12K 1%; R_0805_2012Metric
R53: 100; R_0805_2012Metric
R55: 105k; R_0805_2012Metric
R56, R60, R66: 33k; R_0805_2012Metric
R57, R86, R87, R92, R93: 330; R_0805_2012Metric
R58, R62, R64: 100R; R_0805_2012Metric
R59: 210k; R_0805_2012Metric
R65: 178k; R_0805_2012Metric
R67, R68, R76, R77, R78, R79, R80, R81, R82: R_LED; R_0805_2012Metric
R160, R175: 154k; R_0805_2012Metric
R161, R178: 36k; R_0805_2012Metric
R162, R177: 510k; R_0805_2012Metric
R164, R176: 2,2k; R_0805_2012Metric
R165, R173: 34,8k; R_0805_2012Metric
R166, R169, R170, R171, R172: 47k; R_0805_2012Metric
SERVO1, SERVO2, SERVO3, SERVO4: Conn_01x03_Socket; JST_PH_B3B-PH-K_1x03_P2.00mm_Vertical
TP5, TP6, TP12, TP13, TP16: TestPoint; TestPoint_Pad_D2.0mm
U15, U16, U17, U18, U19, U20, U21, U22, U23, U24, U25, U26, U27, U28, U29, U30: INA226; VSSOP-10_3x3mm_P0.5mm
U31, U33, U34: AP64501SP-13; SOIC-8-1EP_3.9x4.9mm_P1.27mm_EP2.95x4.9mm_Mask2.71x3.4mm_Th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
U35, U40, U41, U42, U43, U44: AP22815AWU; SOT-23-6
U36, U39: LTC3119EFE_PBF; SOP65P640X120-29N
U48, U49, U50, U51: TMC2240_SILENTSTEPSTICK; TMC2209
U52: TB6612FNG; SSOP-24_5.3x8.2mm_P0.65mm
U53: MCP23S17_SO; SSOP-28_3.9x9.9mm_P0.635mm
U67: PCA9685PW; TSSOP-28_4.4x9.7mm_P0.65mm

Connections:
3V3_M.2: J14.38, J14.39, J14.40, J14.41, J14.42, J14.43, R47.1, U29.8 (Vbus), U29.10 (Vin+)
3v3: C38.1, C40.1, C53.1, C57.1, C59.1, J26.1, L1.2, R38.2, R47.2, R53.1, R55.1, TP12.1, U20.9 (Vin-), U29.9 (Vin-)
5V1: C22.1, C23.2, C24.1, C25.2, C26.1, C27.2, C28.1, C29.2, C30.1, C31.2, C32.1, C33.2, C34.1, C35.2, C36.1, C37.2, J14.55, J14.56, R34.1, U15.6 (VS), U16.1 (A1), U16.2 (A0), U16.6 (VS), U16.8 (Vbus), U16.10 (Vin+), U17.6 (VS), U18.1 (A1), U18.6 (VS), U19.2 (A0), U19.6 (VS), U20.6 (VS), U21.1 (A1), U21.6 (VS), U22.6 (VS), U23.2 (A0), U23.6 (VS), U24.6 (VS), U25.6 (VS), U26.6 (VS), U27.1 (A1), U27.6 (VS), U28.2 (A0), U28.6 (VS), U29.6 (VS), U30.6 (VS), U41.6 (IN), U44.6 (IN)
5v: C72.1, C74.1, C76.1, C114.1, C115.1, DSW1.7, J26.2, L3.2, R34.2, R37.2, R43.2, R45.2, R57.1, R65.1, TP13.1, U16.9 (Vin-), U19.9 (Vin-), U25.9 (Vin-), U27.9 (Vin-)
/12v_1: C147.1, C148.1, C149.1, C150.1, J26.6, R33.2, R40.2, R162.1, R163.1, R164.1, TP5.1, U15.9 (Vin-), U22.9 (Vin-), U36.6 (PVOUT), U36.7 (PVOUT)
/12v_2: C156.1, C157.1, C158.1, C159.1, R36.2, R46.2, R174.1, R176.1, R177.1, TP6.1, U18.9 (Vin-), U28.9 (Vin-), U39.6 (PVOUT), U39.7 (PVOUT)
/INA226/-1000010: R44.2, U26.9 (Vin-)
/INA226/-1000111: J26.3, J26.4, R39.2, U21.9 (Vin-)
/PSUs/3v3_enable: DSW1.15, R169.1, U31.3 (EN)
/PSUs/5v_enable: DSW1.14, R170.1, U34.3 (EN)
/PSUs/12v_v1_enable: DSW1.12, R166.2, U36.18 (RUN)
/PSUs/12v_v2_enable: DSW1.11, R172.2, U39.18 (RUN)
/PSUs/servo_enable: DSW1.13, R171.1, U33.3 (EN)
/SW_N: DSW1.1, J1.2 (POS)
/SW_P: DSW1.16, J1.1 (NEG)
/YD-ESP32-S3/4x tmc5161/M1_CS: U48.13 (Chip_select), U53.21 (GPA0)
/YD-ESP32-S3/4x tmc5161/M1_EN: R85.1, U48.16 (Enable), U53.1 (GPB0)
/YD-ESP32-S3/4x tmc5161/M2_CS: U50.13 (Chip_select), U53.22 (GPA1)
/YD-ESP32-S3/4x tmc5161/M2_EN: R90.1, U50.16 (Enable), U53.2 (GPB1)
/YD-ESP32-S3/4x tmc5161/M3_CS: U49.13 (Chip_select), U53.23 (GPA2)
/YD-ESP32-S3/4x tmc5161/M3_EN: R84.1, U49.16 (Enable), U53.3 (GPB2)
/YD-ESP32-S3/4x tmc5161/M4_CS: U51.13 (Chip_select), U53.24 (GPA3)
/YD-ESP32-S3/4x tmc5161/M4_EN: R91.1, U51.16 (Enable), U53.4 (GPB3)
/YD-ESP32-S3/H-bridge/AIN1: U52.21 (AIN1), U53.28 (GPA7)
/YD-ESP32-S3/H-bridge/AIN2: U52.22 (AIN2), U53.27 (GPA6)
/YD-ESP32-S3/H-bridge/BIN1: U52.17 (BIN1), U53.26 (GPA5)
/YD-ESP32-S3/H-bridge/BIN2: U52.16 (BIN2), U53.25 (GPA4)
/YD-ESP32-S3/I2C_SCL_sensors: J14.10, U67.27 (SDA)
/YD-ESP32-S3/I2C_SDA_sensors: J14.9, U67.26 (SCL)
/YD-ESP32-S3/I2C_devices/PCA9531PW/SM1_PWM: SERVO1.2, U67.6 (LED0)
/YD-ESP32-S3/I2C_devices/PCA9531PW/SM2_PWM: SERVO2.2, U67.7 (LED1)
/YD-ESP32-S3/I2C_devices/PCA9531PW/SM3_PWM: SERVO3.2, U67.8 (LED2)
/YD-ESP32-S3/I2C_devices/PCA9531PW/SM4_PWM: SERVO4.2, U67.9 (LED3)
/YD-ESP32-S3/M1_dir: U48.9 (DIR), U53.5 (GPB4)
/YD-ESP32-S3/M1_step: J14.17, U48.10 (STEP)
/YD-ESP32-S3/M2_dir: U50.9 (DIR), U53.6 (GPB5)
/YD-ESP32-S3/M2_step: J14.16, U50.10 (STEP)
/YD-ESP32-S3/M3_dir: U49.9 (DIR), U53.7 (GPB6)
/YD-ESP32-S3/M3_step: J14.15, U49.10 (STEP)
/YD-ESP32-S3/M4_dir: U51.9 (DIR), U53.8 (GPB7)
/YD-ESP32-S3/M4_step: J14.14, U51.10 (STEP)
/YD-ESP32-S3/MCP_RST: J14.20, U53.18 (~RESET)
/YD-ESP32-S3/PWMA: J14.19, U52.23 (PWMA)
/YD-ESP32-S3/PWMB: J14.18, U52.15 (PWMB)
/YD-ESP32-S3/SPI_2_CLK: J14.7, U53.12 (SCK)
/YD-ESP32-S3/SPI_2_MISO: J14.5, U53.14 (SO)
/YD-ESP32-S3/SPI_2_MOSI: J14.6, U53.13 (SI)
/YD-ESP32-S3/Shift_registers/JB_leds/+12V: DC1.2, R67.1, R68.1, R76.1, R77.1, R78.1, R79.1, R80.1, R81.1, R82.1, U35.1 (OUT)
/YD-ESP32-S3/TMC_MISO: J14.2, U48.11 (MISO), U49.11 (MISO), U50.11 (MISO), U51.11 (MISO)
/YD-ESP32-S3/TMC_MOSI: J14.4, U48.15 (MOSI), U49.15 (MOSI), U50.15 (MOSI), U51.15 (MOSI)
/YD-ESP32-S3/TMC_SPI_CLK: J14.3, U48.14 (Spi_clk), U49.14 (Spi_clk), U50.14 (Spi_clk), U51.14 (Spi_clk)
/servo: C45.1, C48.1, C51.1, C55.1, C56.1, C61.1, C62.1, C63.1, J26.5, L4.2, R35.2, R41.2, R42.2, R48.2, R50.1, R59.1, TP16.1, U17.9 (Vin-), U23.9 (Vin-), U24.9 (Vin-), U30.9 (Vin-)
B-B_2: J14.31, U44.4 (EN)
B-B_3: J14.30, U43.4 (EN)
B-B_4: J14.29, U42.4 (EN)
B-B_5: J14.28, U41.4 (EN)
B-B_6: J14.27, U40.4 (EN)
B-B_7: J14.26, U35.4 (EN)
ESP_3v3: C100.1, C101.1, C141.1, CT5.1, J14.36, J14.37, R38.1, R62.2, R86.2, R87.2, R88.2, R89.2, R92.2, R93.2, R94.2, R95.2, U20.8 (Vbus), U20.10 (Vin+), U40.6 (IN), U43.6 (IN), U48.2 (VIO/VDD), U49.2 (VIO/VDD), U50.2 (VIO/VDD), U51.2 (VIO/VDD), U52.20 (VCC), U53.9 (VDD), U67.2 (A1), U67.5 (A4), U67.24 (A5), U67.28 (VDD)
ESP_5v: J14.48, J14.49, R37.1, R58.1, U19.8 (Vbus), U19.10 (Vin+)
GND: C22.2, C23.1, C24.2, C25.1, C26.2, C27.1, C28.2, C29.1, C30.2, C31.1, C32.2, C33.1, C34.2, C35.1, C36.2, C37.1, C38.2, C40.2, C44.2, C45.2, C46.2, C47.2, C48.2, C49.2, C50.2, C51.2, C52.2, C56.2, C57.2, C59.2, C61.2, C62.2, C63.2, C66.2, C68.2, C70.2, C74.2, C76.2, C96.2, C97.2, C98.2, C99.2, C100.2, C101.2, C114.2, C115.2, C141.2, C147.2, C148.2, C149.2, C150.2, C151.2, C152.2, C156.2, C157.2, C158.2, C159.2, CT5.2, D13.1 (K), D14.1 (K), D15.1 (K), D19.1 (K), D22.1 (K), D25.1 (K), D28.1 (K), D31.1 (K), D34.1 (K), D37.1 (K), D40.1 (K), D43.1 (K), DC1.1, DC2.1, DC3.1, DC4.1, DC5.1, DC6.1, DSW1.9, J14.1, J14.8, J14.13, J14.33, J14.34, J14.35, J14.44, J14.45, J14.46, J14.47, J14.57, J14.58, J14.59, J14.60, J14.MP (MountPin), J25.1, R14.2, R56.2, R60.2, R66.2, R84.2, R85.2, R90.2, R91.2, R165.1, R166.1, R169.2, R170.2, R171.2, R172.1, R173.1, SERVO1.3, SERVO2.3, SERVO3.3, SERVO4.3, U15.1 (A1), U15.2 (A0), U15.7 (GND), U16.7 (GND), U17.7 (GND), U18.2 (A0), U18.7 (GND), U19.7 (GND), U20.7 (GND), U21.7 (GND), U22.2 (A0), U22.7 (GND), U23.7 (GND), U24.7 (GND), U25.2 (A0), U25.7 (GND), U26.1 (A1), U26.7 (GND), U27.7 (GND), U28.1 (A1), U28.7 (GND), U29.7 (GND), U30.1 (A1), U30.7 (GND), U31.7 (GND), U31.9 (EP), U33.7 (GND), U33.9 (EP), U34.7 (GND), U34.9 (EP), U35.2 (GND), U36.4 (PGND), U36.9 (PGND), U36.14 (SGND), U36.20 (PGND), U36.25 (PGND), U36.28 (PWM/SYNC), U36.29 (PGND), U39.4 (PGND), U39.9 (PGND), U39.14 (SGND), U39.20 (PGND), U39.25 (PGND), U39.28 (PWM/SYNC), U39.29 (PGND), U40.2 (GND), U41.2 (GND), U42.2 (GND), U43.2 (GND), U44.2 (GND), U48.1 (GND), U48.7 (GND), U49.1 (GND), U49.7 (GND), U50.1 (GND), U50.7 (GND), U51.1 (GND), U51.7 (GND), U52.3 (PGND1), U52.4 (PGND1), U52.9 (PGND2), U52.10 (PGND2), U52.18 (GND), U53.10 (VSS), U53.15 (A0), U53.16 (A1), U53.17 (A2), U67.1 (A0), U67.3 (A2), U67.4 (A3), U67.14 (VSS)
H-bridge: R39.1, U21.8 (Vbus), U21.10 (Vin+), U52.13 (VM2), U52.14 (VM3), U52.24 (VM1)
H_EN: J14.22, U52.19 (STBY)
I2C_RST: J14.21, R14.1, U67.23 (~OE)
INA226_ALERT: J14.32, U15.3 (~Alert), U16.3 (~Alert), U17.3 (~Alert), U18.3 (~Alert), U19.3 (~Alert), U20.3 (~Alert), U21.3 (~Alert), U22.3 (~Alert), U23.3 (~Alert), U24.3 (~Alert), U25.3 (~Alert), U26.3 (~Alert), U27.3 (~Alert), U28.3 (~Alert), U29.3 (~Alert), U30.3 (~Alert)
INA226_SCL: J14.12, U15.4 (SDA), U16.4 (SDA), U17.4 (SDA), U18.4 (SDA), U19.4 (SDA), U20.1 (A1), U20.4 (SDA), U21.2 (A0), U21.4 (SDA), U22.4 (SDA), U23.1 (A1), U23.4 (SDA), U24.2 (A0), U24.4 (SDA), U25.1 (A1), U25.4 (SDA), U26.4 (SDA), U27.4 (SDA), U28.4 (SDA), U29.1 (A1), U29.2 (A0), U29.4 (SDA), U30.2 (A0), U30.4 (SDA)
INA226_SDA: J14.11, U15.5 (SCL), U16.5 (SCL), U17.1 (A1), U17.2 (A0), U17.5 (SCL), U18.5 (SCL), U19.1 (A1), U19.5 (SCL), U20.2 (A0), U20.5 (SCL), U21.5 (SCL), U22.1 (A1), U22.5 (SCL), U23.5 (SCL), U24.1 (A1), U24.5 (SCL), U25.5 (SCL), U26.2 (A0), U26.5 (SCL), U27.2 (A0), U27.5 (SCL), U28.5 (SCL), U29.5 (SCL), U30.5 (SCL)
INPUT_VOLTAGE: DSW1.2, DSW1.3, DSW1.4, DSW1.5, DSW1.6, R44.1, U26.8 (Vbus), U26.10 (Vin+), U31.2 (VIN), U33.2 (VIN), U34.2 (VIN), U36.19 (VIN), U36.22 (PVIN), U36.23 (PVIN), U39.19 (VIN), U39.22 (PVIN), U39.23 (PVIN)
MCP_CS: J14.24, U53.11 (~CS)
Motor 1 power: C96.1, R40.1, U22.8 (Vbus), U22.10 (Vin+), U35.6 (IN), U48.8 (VMOT)
Motor 2 power: C98.1, R46.1, U28.8 (Vbus), U28.10 (Vin+), U42.6 (IN), U50.8 (VMOT)
Motor 3 power: C97.1, R33.1, U15.8 (Vbus), U15.10 (Vin+), U49.8 (VMOT)
Motor 4 power: C99.1, R36.1, U18.8 (Vbus), U18.10 (Vin+), U51.8 (VMOT)
unnamed: C41.1, R49.2
unnamed: C43.1, R51.2
unnamed: C50.1, R52.2
unnamed: C52.1, R54.2
unnamed: C64.1, R61.2
unnamed: C70.1, R63.2
unnamed: C144.1, L6.1, U36.21 (SW1), U36.24 (SW1)
unnamed: C145.1, L6.2, U36.5 (SW2), U36.8 (SW2)
unnamed: C146.1, R160.2
unnamed: C146.2, R161.2
unnamed: C153.1, L7.1, U39.21 (SW1), U39.24 (SW1)
unnamed: C154.1, L7.2, U39.5 (SW2), U39.8 (SW2)
unnamed: C155.1, R175.2
unnamed: C155.2, R178.2
unnamed: D7.2 (A), R164.2
unnamed: D7.1 (K), R163.2, U36.10 (PGOOD)
unnamed: D8.2 (A), R86.1
unnamed: D8.1 (K), R88.1, U48.17 (DIAG)
unnamed: D9.2 (A), R87.1
unnamed: D9.1 (K), R89.1, U49.17 (DIAG)
unnamed: D10.2 (A), R92.1
unnamed: D10.1 (K), R94.1, U50.17 (DIAG)
unnamed: D11.2 (A), R93.1
unnamed: D11.1 (K), R95.1, U51.17 (DIAG)
unnamed: D12.2 (A), R176.2
unnamed: D12.1 (K), R174.2, U39.10 (PGOOD)
unnamed: D13.2 (A), R50.2
unnamed: D14.2 (A), R53.2
unnamed: D15.2 (A), R57.2
unnamed: D17.2 (A), R67.2
unnamed: D17.1 (K), D18.2 (A)
unnamed: D18.1 (K), D19.2 (A)
unnamed: D20.2 (A), R68.2
unnamed: D20.1 (K), D21.2 (A)
unnamed: D21.1 (K), D22.2 (A)
unnamed: D23.2 (A), R76.2
unnamed: D23.1 (K), D24.2 (A)
unnamed: D24.1 (K), D25.2 (A)
unnamed: D26.2 (A), R77.2
unnamed: D26.1 (K), D27.2 (A)
unnamed: D27.1 (K), D28.2 (A)
unnamed: D29.2 (A), R78.2
unnamed: D29.1 (K), D30.2 (A)
unnamed: D30.1 (K), D31.2 (A)
unnamed: D32.2 (A), R79.2
unnamed: D32.1 (K), D33.2 (A)
unnamed: D33.1 (K), D34.2 (A)
unnamed: D35.2 (A), R80.2
unnamed: D35.1 (K), D36.2 (A)
unnamed: D36.1 (K), D37.2 (A)
unnamed: D38.2 (A), R81.2
unnamed: D38.1 (K), D39.2 (A)
unnamed: D39.1 (K), D40.2 (A)
unnamed: D41.2 (A), R82.2
unnamed: D41.1 (K), D42.2 (A)
unnamed: D42.1 (K), D43.2 (A)
unnamed: DC2.2, U40.1 (OUT)
unnamed: DC3.2, U41.1 (OUT)
unnamed: DC4.2, U42.1 (OUT)
unnamed: DC5.2, U43.1 (OUT)
unnamed: DC6.2, U44.1 (OUT)
unnamed: J16.1, U67.10 (LED4)
unnamed: J16.2, U67.11 (LED5)
unnamed: J16.3, U67.12 (LED6)
unnamed: J16.4, U67.13 (LED7)
unnamed: J16.5, U67.15 (LED8)
unnamed: J16.6, U67.16 (LED9)
unnamed: J16.7, U67.17 (LED10)
unnamed: J16.8, U67.18 (LED11)
unnamed: J16.9, U67.19 (LED12)
unnamed: J16.10, U67.20 (LED13)
unnamed: J16.11, U67.21 (LED14)
unnamed: J16.12, U67.22 (LED15)
unnamed: J25.3, Q1.1 (D), R58.2
unnamed: J31.1, U52.5 (AO2), U52.6 (AO2)
unnamed: J31.2, U52.1 (AO1), U52.2 (AO1)
unnamed: J32.1, U52.7 (BO2), U52.8 (BO2)
unnamed: J32.2, U52.11 (BO1), U52.12 (BO1)
unnamed: M4.3 (-), U48.3 (M1B)
unnamed: M5.3 (-), U49.3 (M1B)
unnamed: M6.3 (-), U50.3 (M1B)
unnamed: M7.3 (-), U51.3 (M1B)
unnamed: Q1.2 (G), Q1.3 (S), R62.1, R64.1
unnamed: C41.2, U31.1 (BST)
unnamed: C47.1, R52.1, U31.6 (COMP)
unnamed: C53.2, R55.2, R56.1, U31.5 (FB)
unnamed: C44.1, U31.4 (SS)
unnamed: L1.1, R49.1, U31.8 (SW)
unnamed: C43.2, U33.1 (BST)
unnamed: C49.1, R54.1, U33.6 (COMP)
unnamed: C55.2, R59.2, R60.1, U33.5 (FB)
unnamed: C46.1, U33.4 (SS)
unnamed: L4.1, R51.1, U33.8 (SW)
unnamed: C64.2, U34.1 (BST)
unnamed: C68.1, R63.1, U34.6 (COMP)
unnamed: C72.2, R65.2, R66.1, U34.5 (FB)
unnamed: C66.1, U34.4 (SS)
unnamed: L3.1, R61.1, U34.8 (SW)
unnamed: C144.2, U36.26 (BST1)
unnamed: C145.2, U36.3 (BST2)
unnamed: R161.1, R162.2, U36.12 (FB)
unnamed: C151.1, U36.11 (SVCC), U36.15 (MPPC), U36.16 (VCC)
unnamed: R165.2, U36.17 (RT)
unnamed: R160.1, U36.13 (VC)
unnamed: C153.2, U39.26 (BST1)
unnamed: C154.2, U39.3 (BST2)
unnamed: R177.2, R178.1, U39.12 (FB)
unnamed: C152.1, U39.11 (SVCC), U39.15 (MPPC), U39.16 (VCC)
unnamed: R173.2, U39.17 (RT)
unnamed: R175.1, U39.13 (VC)
unnamed: M4.6, U48.6 (M1A)
unnamed: M4.4, U48.5 (M2A)
unnamed: M4.1, U48.4 (M2B)
unnamed: M5.6, U49.6 (M1A)
unnamed: M5.4, U49.5 (M2A)
unnamed: M5.1, U49.4 (M2B)
unnamed: M6.6, U50.6 (M1A)
unnamed: M6.4, U50.5 (M2A)
unnamed: M6.1, U50.4 (M2B)
unnamed: M7.6, U51.6 (M1A)
unnamed: M7.4, U51.5 (M2A)
unnamed: M7.1, U51.4 (M2B)
RPI_5V: J14.50, J14.51, J14.52, J14.53, J14.54, R45.1, U27.8 (Vbus), U27.10 (Vin+)
SERVO1: R35.1, SERVO1.1, U17.8 (Vbus), U17.10 (Vin+)
SERVO2: R42.1, SERVO2.1, U24.8 (Vbus), U24.10 (Vin+)
SERVO3: R48.1, SERVO3.1, U30.8 (Vbus), U30.10 (Vin+)
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

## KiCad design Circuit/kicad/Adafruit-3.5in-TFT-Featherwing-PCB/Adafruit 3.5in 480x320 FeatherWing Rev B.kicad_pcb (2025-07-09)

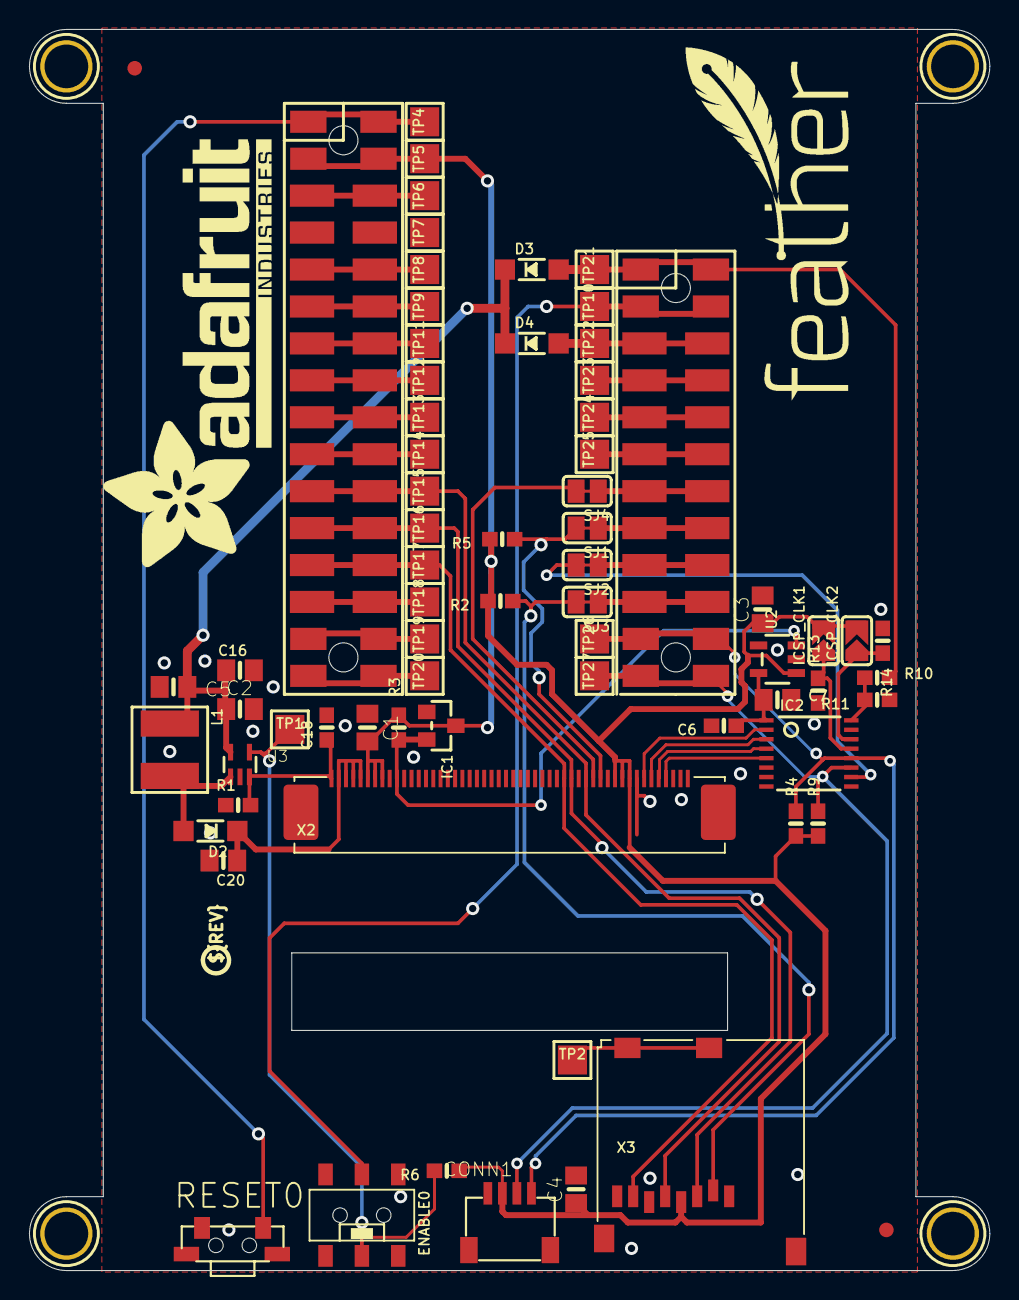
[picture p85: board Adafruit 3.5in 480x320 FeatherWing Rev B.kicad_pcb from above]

Board: 16 copper layers, 66.0 x 85.3 mm, 92 parts (1 on the bottom side), 47 nets.

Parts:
C1, C16, C20: 1uF; 0805-NO
C2, C3, C4, C5, C7: 10uF; 0805-NO
C6, C18: 0.1uF; 0603-NO
CONN1: STEMMA_I2C_QT; JST_SH4
D2, D3, D4: MBR0540; SOD-123
ENABLE0: Slide Switch; EG1390
IC1: RESET_SUPERVISORAPX80X_SA; SOT23-WIDE
IC2: TSC2007PW; TSSOP16
ICSP_CLK1: A1; SOLDERJUMPER_ARROW_NOPASTE
ICSP_CLK2: A0; SOLDERJUMPER_ARROW_NOPASTE
L1: 6.8uH; INDUCTOR_5X5MM_NR5040_NOTHERMALS
MS2: FEATHERWING_SMTDUAL; FEATHERWING_SMT2
PLABEL0: PLABEL0
PLABEL1: PLABEL1
PLABEL2: PLABEL2
PLABEL3: PLABEL3
PLABEL4: PLABEL4
PLABEL5: PLABEL5
PLABEL6: PLABEL6
PLABEL7: PLABEL7
PLABEL8: PLABEL8
PLABEL9: PLABEL9
PLABEL10: PLABEL10
PLABEL11: PLABEL11
PLABEL12: PLABEL12
PLABEL13: PLABEL13
PLABEL14: PLABEL14
PLABEL15: PLABEL15
R1: 8.2 ohm; 0603-NO
R2, R5, R6, R10, R11: 100K; 0603-NO
R3, R4, R9, R13, R14: 10K; 0603-NO
RESET0: SPST_RA; SPST_TACTILE_RA
SJ1, SJ2, SJ3, SJ4: SOLDERJUMPER_CLOSEDWIRE
TP1, TP2, TP4, TP5, TP6, TP7, TP8, TP9, TP10, TP11, TP12, TP13, TP14, TP15, TP16, TP17, TP18, TP19, TP20, TP21, TP22, TP23, TP24, TP25, TP26, TP27: TESTPOINT_PAD_2MM
U2: AP2127K-3.3; SOT23-5
U3: TPS61169; SC70-5
U$7, U$15, U$16, U$17: MOUNTINGHOLE3.0THIN; MOUNTINGHOLE_3.0_PLATEDTHIN
U$9, U$23: FIDUCIAL_1MM
U$11: FEATHERLOGO
U$19: ADAFRUIT_TEXT_30MM
U$37: PCBFEAT-REV-040
X2: 3.5" TFT; TFT_3.5IN_320X480_50PIN
X3: MicroSD; MICROSD

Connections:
3.3V: C1.1, C3.1, C4.1, CONN1.2, IC1.3, ICSP_CLK1.2, ICSP_CLK2.2, MS2.2, MS2.2', R2.2, R3.2, R4.1, R5.2, R6.1, R9.1, TP5.P$1, U2.1, X2.6, X2.7, X2.8, X2.40, X2.41, X2.42, X3.4
+5V: C2.1, C5.1, C16.1, D3.C, D4.C, L1.P$1, U3.5
+24V: C20.1, D2.C, X2.2, X2.3, X2.4, X2.5
A: MS2.5, MS2.5', TP8.P$1
ADDR0: IC2.14, ICSP_CLK2.1, R14.2
ADDR1: IC2.13, ICSP_CLK1.1, R13.2
AREF: MS2.3, MS2.3', TP6.P$1
AUX: IC2.16, R10.1, R11.2
B: MS2.6, MS2.6', TP9.P$1
C: MS2.7, MS2.7', TP11.P$1
CARDDET: TP2.P$1, X3.CD1, X3.CD2
D: MS2.8, MS2.8', TP12.P$1
E: MS2.9, MS2.9', TP13.P$1
EN: ENABLE0.P2, MS2.27, MS2.27', TP10.P$1
F: MS2.10, MS2.10', TP14.P$1
G: MS2.16, MS2.16', TP20.P$1
GND: C1.2, C2.2, C3.2, C4.2, C5.2, C6.2, C7.2, C16.2, C18.2, C20.2, CONN1.1, CONN1.MT1, CONN1.MT2, ENABLE0.S1, ENABLE0.S2, IC1.1, IC2.6, MS2.4, MS2.4', R1.1, R11.1, R13.1, R14.1, RESET0.1, RESET0.MT1, RESET0.MT2, TP7.P$1, U2.2, U3.2, X2.43, X2.48, X2.49, X2.50, X3.6, X3.MT1, X3.MT2
H: MS2.19, MS2.19', SJ3.1
I: MS2.20, MS2.20', SJ2.1
J: MS2.21, MS2.21', SJ1.1
K: MS2.22, MS2.22', SJ4.1
L: MS2.23, MS2.23', TP25.P$1
LCD_LITE: ENABLE0.P1, R6.2, TP1.P$1, U3.4
LEDK: C18.1, R1.2, U3.3, X2.1
M: MS2.24, MS2.24', TP24.P$1
MISO: MS2.13, MS2.13', TP17.P$1, X2.33, X3.7
MOSI: MS2.12, MS2.12', TP16.P$1, X2.34, X3.3
N: MS2.25, MS2.25', TP23.P$1
unnamed: D2.A, L1.P$2, U3.1
RT_INT: IC2.10, SJ2.2
RX: MS2.14, MS2.14', TP18.P$1
SCL: CONN1.4, IC2.12, MS2.18, MS2.18', R4.2, TP26.P$1
SCLK: MS2.11, MS2.11', TP15.P$1, X2.36, X3.5
SDA: CONN1.3, IC2.11, MS2.17, MS2.17', R9.2, TP27.P$1
SD_CS: R2.1, SJ3.2, X3.2
TFT_CS: R5.1, SJ1.2, X2.38
TFT_DC: SJ4.2, X2.37
TSC_PWR: C6.1, C7.1, IC2.1, U2.5
TX: MS2.15, MS2.15', TP19.P$1
USB: D4.A, MS2.26, MS2.26', TP22.P$1
VBAT: D3.A, MS2.28, MS2.28', R10.2, TP21.P$1
XL: IC2.4, X2.46
XR: IC2.2, X2.44
YD: IC2.3, X2.45
YU: IC2.5, X2.47
~RESET: MS2.1, MS2.1', RESET0.2, TP4.P$1
~TFT_RST: IC1.2, R3.1, U2.3, X2.10

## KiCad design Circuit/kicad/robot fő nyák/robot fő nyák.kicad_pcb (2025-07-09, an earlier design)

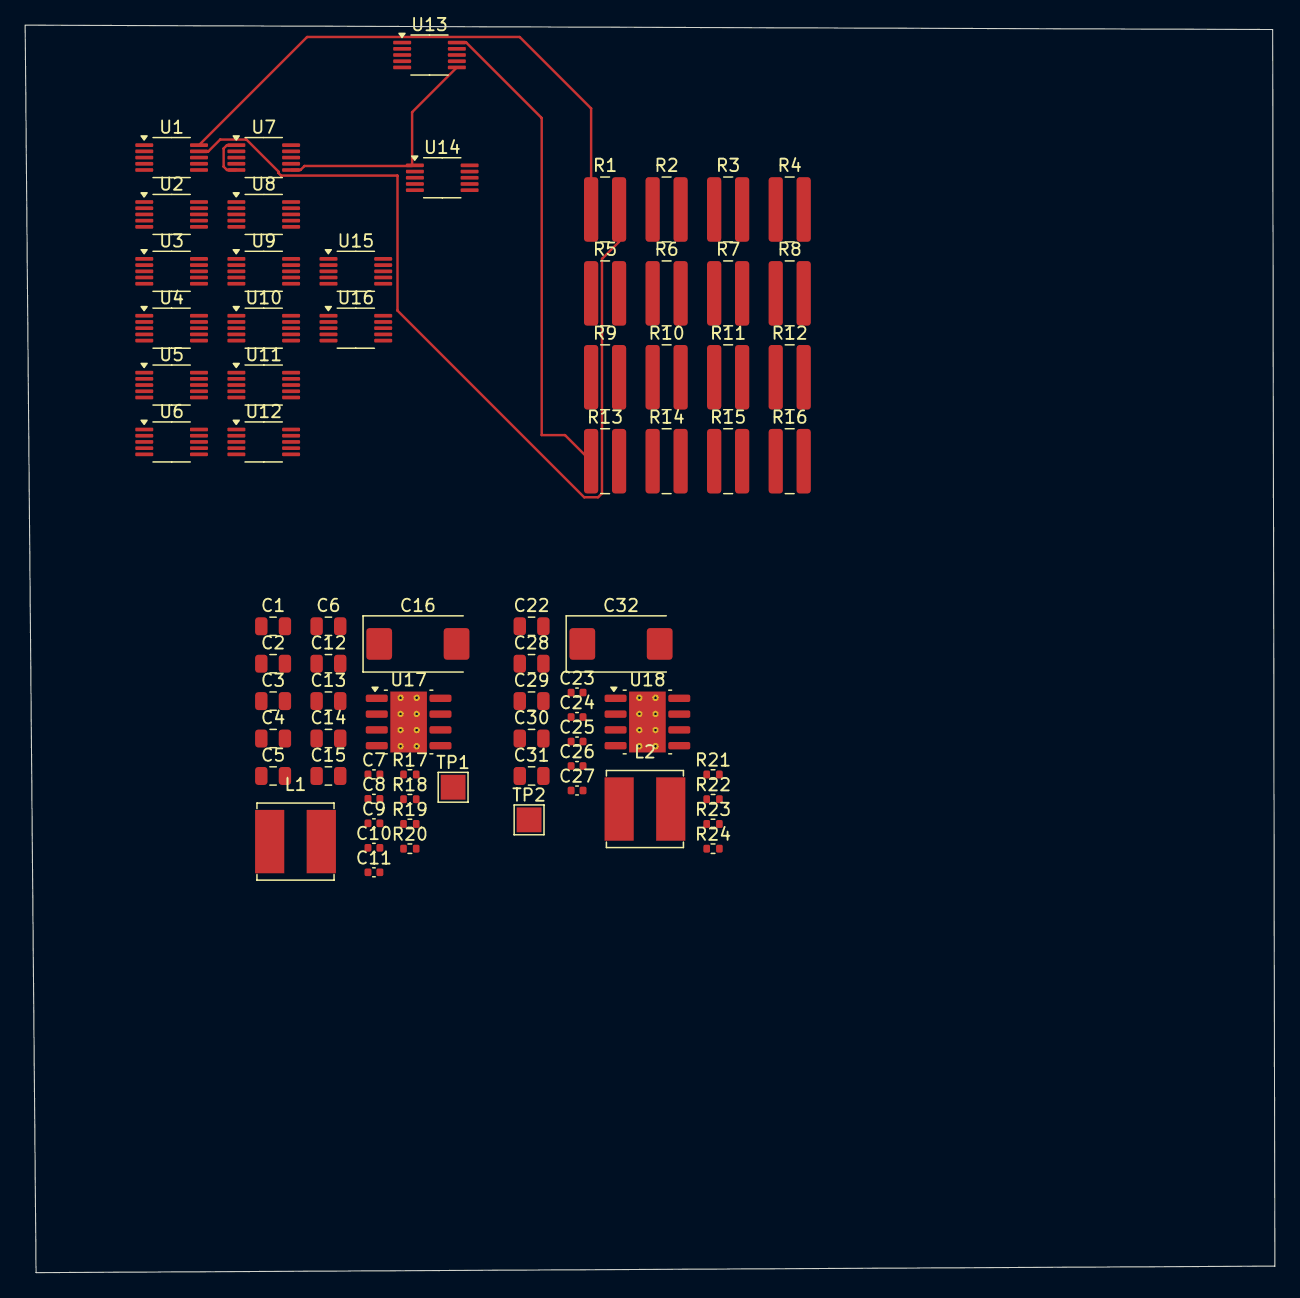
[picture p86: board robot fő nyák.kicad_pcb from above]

Board: 2 copper layers, 100.5 x 100.4 mm, 73 parts (0 on the bottom side), 47 nets.

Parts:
C1, C2, C3, C4, C5, C6: 10u 35v; C_0805_2012Metric
C7, C8, C23, C24: 100n; C_0402_1005Metric
C9, C11, C25, C27: nf; C_0402_1005Metric
C10, C26: 1.2nF; C_0402_1005Metric
C12, C13, C14, C15, C28, C29, C30, C31: 10u; C_0805_2012Metric
C16, C32: 100uF; CP_EIA-7343-31_Kemet-D
C22: 100uF 16V; C_0805_2012Metric
L1, L2: SRN6045TA-3R3Y; L_Bourns_SRN6045TA
R1, R2, R3, R4, R5, R6, R7, R8, R9, R10, R11, R12, R13, R14, R15, R16: 0.025Ω; R_1020_2550Metric
R17, R21: 10R; R_0402_1005Metric
R18, R22: 20K 1%; R_0402_1005Metric
R19: 12K 1%; R_0402_1005Metric
R20: 2.2K 1%; R_0402_1005Metric
R23: 10K 1%; R_0402_1005Metric
R24: 3K 1%; R_0402_1005Metric
TP1, TP2: TestPoint; TestPoint_Pad_2.0x2.0mm
U1, U2, U3, U4, U5, U6, U7, U8, U9, U10, U11, U12, U13, U14, U15, U16: INA226; VSSOP-10_3x3mm_P0.5mm
U17, U18: AP64501SP-13; SOIC-8-1EP_3.9x4.9mm_P1.27mm_EP2.95x4.9mm_Mask2.71x3.4mm_Th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

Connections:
5V1: U1.6 (VS), U2.1 (A1), U2.6 (VS), U3.6 (VS), U4.6 (VS), U5.2 (A0), U5.6 (VS), U6.1 (A1), U6.2 (A0), U6.6 (VS), U7.2 (A0), U7.6 (VS), U8.2 (A0), U8.6 (VS), U9.6 (VS), U10.1 (A1), U10.6 (VS), U11.6 (VS), U12.6 (VS), U13.6 (VS), U14.1 (A1), U14.6 (VS), U15.6 (VS), U16.6 (VS)
/3v3_psu/3V3_psu: C27.1, C28.1, C29.1, C30.1, C31.1, C32.1, L2.2, R7.2, R23.1, TP2.1, U7.9 (Vin-)
/3v3_psu/bat in +: C1.1, C2.1, C3.1, C4.1, C5.1, C6.1, C22.1, R9.1, U9.8 (Vbus), U9.10 (Vin+), U17.2 (VIN), U17.3 (EN), U18.2 (VIN), U18.3 (EN)
/4pcs TMC2240/M2+: R5.1, U5.8 (Vbus), U5.10 (Vin+)
/4pcs TMC2240/M3+: R3.1, U3.8 (Vbus), U3.10 (Vin+)
/4pcs TMC2240/M4+: R4.1, U4.8 (Vbus), U4.10 (Vin+)
/5V_psu/5V_psu +: C11.1, C12.1, C13.1, C14.1, C15.1, C16.1, L1.2, R14.2, R19.1, TP1.1, U14.9 (Vin-)
/INA226/+1000000: R1.1, U1.8 (Vbus), U1.10 (Vin+)
/INA226/+1000011: R13.1, U13.8 (Vbus), U13.10 (Vin+)
/INA226/+1000100: R2.1, U2.8 (Vbus), U2.10 (Vin+)
/INA226/+1000101: R6.1, U6.8 (Vbus), U6.10 (Vin+)
/INA226/+1000110: R10.1, U10.8 (Vbus), U10.10 (Vin+)
/INA226/+1000111: R14.1, U14.8 (Vbus), U14.10 (Vin+)
/INA226/+1001001: R7.1, U7.8 (Vbus), U7.10 (Vin+)
/INA226/+1001010: R11.1, U11.8 (Vbus), U11.10 (Vin+)
/INA226/+1001011: R15.1, U15.8 (Vbus), U15.10 (Vin+)
/INA226/+1001101: R8.1, U8.8 (Vbus), U8.10 (Vin+)
/INA226/+1001110: R12.1, U12.8 (Vbus), U12.10 (Vin+)
/INA226/+1001111: R16.1, U16.8 (Vbus), U16.10 (Vin+)
/INA226/-1000000: R1.2, R3.2, R4.2, R5.2, R9.2, U1.9 (Vin-), U3.9 (Vin-), U4.9 (Vin-), U5.9 (Vin-), U9.9 (Vin-)
/INA226/-1000011: R13.2, U13.9 (Vin-)
/INA226/-1000100: R2.2, U2.9 (Vin-)
/INA226/-1000101: R6.2, U6.9 (Vin-)
/INA226/-1000110: R10.2, U10.9 (Vin-)
/INA226/-1001010: R11.2, U11.9 (Vin-)
/INA226/-1001011: R15.2, U15.9 (Vin-)
/INA226/-1001101: R8.2, U8.9 (Vin-)
/INA226/-1001110: R12.2, U12.9 (Vin-)
/INA226/-1001111: R16.2, U16.9 (Vin-)
/INA226/alert out: U1.3 (~Alert), U2.3 (~Alert), U3.3 (~Alert), U4.3 (~Alert), U5.3 (~Alert), U6.3 (~Alert), U7.3 (~Alert), U8.3 (~Alert), U9.3 (~Alert), U10.3 (~Alert), U11.3 (~Alert), U12.3 (~Alert), U13.3 (~Alert), U14.3 (~Alert), U15.3 (~Alert), U16.3 (~Alert)
GND: C1.2, C2.2, C3.2, C4.2, C5.2, C6.2, C8.2, C9.2, C10.2, C12.2, C13.2, C14.2, C15.2, C16.2, C22.2, C24.2, C25.2, C26.2, C28.2, C29.2, C30.2, C31.2, C32.2, R20.2, R24.2, U1.1 (A1), U1.2 (A0), U1.7 (GND), U2.2 (A0), U2.7 (GND), U3.2 (A0), U3.7 (GND), U4.2 (A0), U4.7 (GND), U5.1 (A1), U5.7 (GND), U6.7 (GND), U7.7 (GND), U8.7 (GND), U9.1 (A1), U9.7 (GND), U10.7 (GND), U11.7 (GND), U12.7 (GND), U13.1 (A1), U13.7 (GND), U14.7 (GND), U15.7 (GND), U16.7 (GND), U17.7 (GND), U17.9 (EP), U18.7 (GND), U18.9 (EP)
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

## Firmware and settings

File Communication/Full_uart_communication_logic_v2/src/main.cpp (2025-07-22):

// File: main.cpp
#include <Arduino.h>
#include "LED.h"
#include "GYRO.h"
#include "COLOR_SENSOR.h"

// --- Protokoll Konstansok ---
// Ezeknek egyezniük kell a Python szkriptben lévőkkel
// Parancsok (RPI -> ESP32)
const uint8_t CMD_PING = 0;
const uint8_t CMD_RESTART = 1;
const uint8_t CMD_READ_GYRO = 2;
const uint8_t CMD_CALIBRATE_GYRO = 3;
const uint8_t CMD_READ_COLOR_SENSOR = 4;
const uint8_t CMD_SET_LED = 7;

// Response (ESP32 -> RPI)
const uint8_t RSP_ACK = 100;         // Sikeres parancs végrehajtás
const uint8_t RSP_PONG = 101;        // Válasz a PING-re
const uint8_t RSP_ERROR = 200;       // Hiba történt (pl. rossz checksum)
const uint8_t RSP_UNKNOWN_CMD = 201; // Ismeretlen parancs


#define RX1_PIN 20
#define TX1_PIN 21

Led led;
BNO08xGyro gyro;
ColorSensor colorSensor;


uint16_t fletcher16(const uint8_t *data, size_t len) {
  uint16_t sum1 = 0;
  uint16_t sum2 = 0;
  for (size_t i = 0; i < len; ++i) {
    sum1 = (sum1 + data[i]) % 255;
    sum2 = (sum2 + sum1) % 255;
  }
  return (sum2 << 8) | sum1;
}


void sendResponse(uint8_t cmd, uint8_t p1 = 0, uint8_t p2 = 0, uint8_t p3 = 0) {
  uint8_t response[7];
  response[0] = 0xAA;    // Start byte
  response[1] = cmd;
  response[2] = p1;
  response[3] = p2;
  response[4] = p3;

  uint16_t checksum = fletcher16(response, 5);
  response[5] = checksum & 0xFF;
  response[6] = (checksum >> 8) & 0xFF;

  Serial1.write(response, 7);
}


void processPacket() {
  /*
  const uint8_t* buffer ez megy a függvényhívásba
  uint16_t received_checksum = (buffer[6] << 8) | buffer[5];
  uint16_t calculated_checksum = fletcher16(buffer, 5);

  if (received_checksum != calculated_checksum) {
    sendResponse(RSP_ERROR); // Hiba küldése rossz checksum esetén
    return;
  }

  uint8_t cmd    = buffer[1];
  uint8_t param1 = buffer[2];
  // uint8_t param2 = buffer[3]; // Jelenleg nincsenek használva
  // uint8_t param3 = buffer[4];
  */
  uint8_t cmd = CMD_READ_COLOR_SENSOR;
  uint8_t param1 = 25;
  uint8_t param2 = 4;

  switch (cmd) {
    case CMD_PING:
      sendResponse(RSP_PONG);
      break;

    case CMD_RESTART:
      sendResponse(RSP_ACK, cmd);
      delay(100);
      ESP.restart();
      break;

    case CMD_READ_GYRO:
      if (gyro.update()) {
        float roll, pitch, yaw;
        gyro.getEuler(roll, pitch, yaw);
        Serial.print("Roll: "); Serial.print(roll);
        Serial.print(" Pitch: "); Serial.print(pitch);
        Serial.print(" Yaw: "); Serial.println(yaw);
      } else {
        Serial.println("Gyro update failed. No new data.");
      }
      break; // HIÁNYZÓ BREAK!
    case CMD_CALIBRATE_GYRO:
      // Példa: 90 fokra kalibrálás
      gyro.calibrateToAngle(param1);
      sendResponse(RSP_ACK, cmd); // Nyugta küldése a kalibráció után
      break;
    case CMD_READ_COLOR_SENSOR:
      uint16_t value;
      colorSensor.readOneChannel(param2, value);
      Serial.print("Color channel ");
      Serial.print(param2);
      Serial.print("value : ");
      Serial.println(value);
      break;
    case CMD_SET_LED:
      led.handleColor(param1);
      // Nyugta: ACK, az eredeti parancsra, az eredeti paraméterrel
      sendResponse(RSP_ACK, cmd, param1);
      break;


    default:
      sendResponse(RSP_UNKNOWN_CMD, cmd); // Ismeretlen parancs jelzése
      break;
  }
}

void setup() {
  Serial.begin(115200);
  Serial1.begin(576000, SERIAL_8N1, RX1_PIN, TX1_PIN);
  led.begin();
  colorSensor.begin();

  gyro.begin();
  led.off();
}

void loop() {
  /*
  static uint8_t buffer[7];
  static uint8_t bytes_received = 0;

  // Nem-blokkoló olvasás a soros portról
  while (Serial1.available() > 0) {
    uint8_t incoming_byte = Serial1.read();

    // Ha szinkronizációs hiba van, keressük a csomag elejét
    if (bytes_received == 0) {
      if (incoming_byte == 0xAA) {
        buffer[0] = incoming_byte;
        bytes_received = 1;
      }
      // Ha nem 0xAA, ignoráljuk, amíg meg nem találjuk
    } else {
      // Gyűjtjük a csomag többi részét
      buffer[bytes_received++] = incoming_byte;
    }

    // Ha a teljes csomag megérkezett
    if (bytes_received == 7) {
      processPacket(buffer);
      bytes_received = 0; // Reset a következő csomag fogadásához
    }
    */
    processPacket();
    delay(100);
  }

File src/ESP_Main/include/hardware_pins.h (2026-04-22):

#pragma once
#include <Arduino.h>

//ESP GPIO pins
const int DM_A0pin = 4;
const int DM_A1pin = 5;
const int DM_A2pin = 6;
const int DM_A3pin = 7;
//Sensor SPI bus
const int Sensor_SPI_MOSI = 38;
const int Sensor_SPI_MISO = 39;
const int Sensor_SPI_CS = 40;
const int Sensor_SPI_SCL = 41;


//for testing
const int BNO_INT = 36;
const int BNO_RST = 35;
const uint8_t TMC_EN = 21;
const uint8_t BME280_CS = 45;


const uint8_t Servo1_pin = 20;




// << ======= >>
// Demultilexer pins
const int DM_ICM_CS = 0; // ICM Gyro-Sensor
const int DM_BNO_CS = 1; // BNO IMU Modul
const int DM_BME280_CS = 2; // BME280 Temperature, Huminydi and pressure sensor
const int DM_AD_MCP_CS = 3; // AD Mcp is a Analog-Digital converter for 10k ntcs
const int DM_SPI1_CS = 4; // SPI Connector 1 Chip Sellect
const int DM_SPI2_CS = 5; // SPI Connector 2 Cship Select
const int DM_SPI3_CS = 6; // SPI Connector 3 Cship Select
const int DM_SPI4_CS = 7; // SPI Connector 4 Cship Select
const int DM_M1_CS = 8; // Stepper motor 1 Chip Select
const int DM_M2_CS = 9; // Stepper motor 2 Chip Select
const int DM_M3_CS = 10; // Stepper motor 3 Chip Select
const int DM_M4_CS = 11; // Stepper motor 4 Chip Select
const int DM_MCP_CS = 12; // MCP IO Expander Chip Select
const int DM_DIAG_LED1 = 13; // Dignostic Led 1
const int DM_DIAG_LED2 = 14; // Dignostic Led 2
const int DM_DIAG3_LED3 = 15; // Dignostic Led 2 (Also Empty Chanel)

// TMC5160
const float TMC_R_SENSE = 0.075;

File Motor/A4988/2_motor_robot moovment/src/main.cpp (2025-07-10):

#include <Arduino.h>
#include <AccelStepper.h>
#define TOUCH_PIN T8

constexpr int DIR_PIN1 = 17;
constexpr int STEP_PIN1 = 16;

constexpr int DIR_PIN2 = 6;
constexpr int STEP_PIN2 = 7;

AccelStepper motor1(AccelStepper::DRIVER, STEP_PIN1, DIR_PIN1);
AccelStepper motor2(AccelStepper::DRIVER, STEP_PIN2, DIR_PIN2);

long currentPos = 0;
int stepSize = 10000;

void moveMotors(long motor1Target, long motor2Target) {
  motor1.moveTo(motor1Target);
  motor2.moveTo(motor2Target);
  while (motor1.distanceToGo() != 0 || motor2.distanceToGo() != 0) {
    motor1.run();
    motor2.run();
  }
  delay(500);
}

void waitForTouch() {
  while (touchRead(TOUCH_PIN) < 30000) {
    Serial.println(touchRead(TOUCH_PIN));
    delay(10);
  }
}

void setup() {


  Serial.begin(115200);
  delay(1000);

  int microstepp = 16;

  motor1.setMaxSpeed(600 * microstepp);
  motor1.setAcceleration(1000 * microstepp);

  motor2.setMaxSpeed(600 * microstepp);
  motor2.setAcceleration(1000 * microstepp);
}


void loop() {
  waitForTouch();
  // Előre
  for (int i = 0; i < 3; i++)
  {
    currentPos += stepSize;
  moveMotors(currentPos, currentPos);
  Serial.println(touchRead(TOUCH_PIN));


  // Hátra
  currentPos -= stepSize;
  moveMotors(currentPos, currentPos);

  // Jobbra
  currentPos += stepSize;
  moveMotors(currentPos, -currentPos);

  // Balra
  currentPos -= stepSize;
  moveMotors(-currentPos, currentPos);
  }
  
  
}

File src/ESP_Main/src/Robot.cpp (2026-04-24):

#include <Robot.h>
#include <Arduino.h>
#include <74HC154.h>
#include <BNO085.h>
#include <hardware_pins.h>
#include <TMC5160.h>
#include <ESP32Servo.h>
#include <SPI.h>

Demux dm(DM_A0pin, DM_A1pin, DM_A2pin, DM_A3pin);

Robot::Robot():
    _L_Motor(9),
    _R_Motor(8),
    _bno(),
    _bme(BME280_CS),
    lecsuko()
{
    
};

void Robot::begin() {
    SPI.begin(Sensor_SPI_SCL, Sensor_SPI_MISO, Sensor_SPI_MOSI);
    pinMode(8, OUTPUT);
    pinMode(9, OUTPUT);
    pinMode(47, OUTPUT);
    pinMode(21, OUTPUT);
    pinMode(48, OUTPUT);
    pinMode(10, OUTPUT);
    Wire.begin(12,11);
    _L_Motor.begin(48);
    _R_Motor.begin(21);
    _L_Motor.stop_motor();
    _R_Motor.stop_motor();
    //driver.shaft(true); 
    dm.begin();
    Serial.begin(115200);
    
    if (_bno.begin()) {
        Serial.println("Sikeres szenzorinicializacio");
    } else {
        Serial.println("Sikertelen inicializacio");
    }
    lecsuko.begin(10);
}




void Robot::ForwawrdCmWithGyro(bool dir, float cm, float speed, float target_angle, int acceleration) {
    const float CORRECTION_VALUE  = 500.0;
    const float ERROR_VALUE       = 0.5;
    const float WHEEL_DIAMETER_CM = 6.5;
    const long  cm_in_steps = (200L * TMC_MICROSTEP) / (WHEEL_DIAMETER_CM * 3.1415);
    long target_steps = cm_in_steps * (long)abs(cm);
    long start_pos    = _L_Motor.driver.XACTUAL();

    // Kompenzáció: a motor a stop_motor() hívása után még halad egy kicsit.
    // Formula újrakalibrálva 100cm mérési adatok alapján:
    //   100000 → 90.5cm, 200000 → 93cm, 300000 → 96.5cm
    // (negatív esetén 0 = nincs kompenzáció)
    long compensation = max(0L, (long)(speed * 0.6145f) - 81516L);
    long stop_at      = (target_steps > compensation) ? (target_steps - compensation) : 0;

    while (abs(_L_Motor.driver.XACTUAL() - start_pos) < stop_at) {
        _bno.update();
        float error = target_angle - _bno.getYaw();
        while (error >  180.0) error -= 360.0;
        while (error < -180.0) error += 360.0;
        float correction = (abs(error) > ERROR_VALUE) ? (error * CORRECTION_VALUE) : 0.0f;

        int32_t sL = (int32_t)(speed + (dir ?  correction : -correction));
        int32_t sR = (int32_t)(speed + (dir ? -correction :  correction));
        if (sL < 0) sL = 0;
        if (sR < 0) sR = 0;

        _L_Motor.rotate_motor(dir, (uint32_t)sL, acceleration);
        _R_Motor.rotate_motor(dir, (uint32_t)sR, acceleration);
        delay(5);
    }

    _L_Motor.stop_motor();
    _R_Motor.stop_motor();
}



void Robot::TurnDegrees(float degrees, uint32_t speed, int acceleration) {
    if (abs(degrees) < 0.5) return; // semmi sem kell ha tul kicsi

    const float WHEEL_DIAMETER_CM = 6.5;
    const float TRACK_WIDTH_CM    = 17.0; // kerékközépponttól kerékközéppontig
    const long  cm_in_steps = (200L * TMC_MICROSTEP) / (WHEEL_DIAMETER_CM * 3.1415);

    // A forduláshoz szükséges ívhossz mindkét keréknek
    float arc_cm    = (abs(degrees) / 360.0f) * 3.1415f * TRACK_WIDTH_CM;
    long  turn_steps = (long)(arc_cm * cm_in_steps);

    Serial.printf("TurnDegrees: %.1f fok, ívhossz=%.2fcm, lepesek=%ld\n",
        degrees, arc_cm, turn_steps);

    long start_pos = _L_Motor.driver.XACTUAL();

    // Pozitív fok → balra fordul (bal hátra, jobb előre)
    // Negatív fok → jobbra fordul (bal előre, jobb hátra)
    bool positive = (degrees > 0);
    if (positive) {
        _L_Motor.rotate_motor(false, speed, acceleration);
        _R_Motor.rotate_motor(true,  speed, acceleration);
    } else {
        _L_Motor.rotate_motor(true,  speed, acceleration);
        _R_Motor.rotate_motor(false, speed, acceleration);
    }

    while (abs(_L_Motor.driver.XACTUAL() - start_pos) < turn_steps) {
        delay(2);
    }

    _L_Motor.stop_motor();
    _R_Motor.stop_motor();
}



void Robot::TurnWithOneWheel(bool use_left_wheel, bool forward, float target_angle, uint32_t max_speed, uint16_t acceleration) {
    bool reached = false;
    const float TOLERANCE = 0.5;
    
    if (use_left_wheel) {
        _R_Motor.stop_motor();
    } else {
        _L_Motor.stop_motor();
    }

    while (!reached) {
        _bno.update();
        float current_yaw = _bno.getYaw();

        float error = target_angle - current_yaw;
        
        if (abs(error) <= TOLERANCE) {
            reached = true;
            break;
        }

        if (use_left_wheel) {
            _L_Motor.rotate_motor(forward, max_speed, acceleration);
        } else {
            _R_Motor.rotate_motor(forward, max_speed, acceleration);
        }

        delay(10);
    }

    if (use_left_wheel) {
        _L_Motor.stop_motor();
    } else {
        _R_Motor.stop_motor();
    }
}

void Robot::MoveUntilHit(bool dir, uint32_t speed, int8_t sensitivity) {
    Serial.println("Indulas a falnak...");
    
    _L_Motor.set_stallguard(sensitivity);
    _R_Motor.set_stallguard(sensitivity);

    _L_Motor.rotate_motor(dir, speed, 2000);
    _R_Motor.rotate_motor(dir, speed, 2000);

    delay(500); 

    bool hit = false;
    unsigned long start_time = millis();

    while (!hit) {
        uint16_t sgL = _L_Motor.get_stall_result();
        uint16_t sgR = _R_Motor.get_stall_result();

        Serial.printf("SG_L: %d, SG_R: %d\n", sgL, sgR);

        if (sgL == 0 || sgR == 0) {
            Serial.println("UTKOZES DETEKTALVA! A robot megakadt.");
            hit = true;
        }

        if (millis() - start_time > 15000) {
            Serial.println("Timeout: Nem talaltam falat.");
            break;
        }
        
        delay(20);
    }

    _L_Motor.stop_motor();
    _R_Motor.stop_motor();

    _L_Motor.driver.en_pwm_mode(1);
    _R_Motor.driver.en_pwm_mode(1);

    _L_Motor.driver.TCOOLTHRS(0);
    _R_Motor.driver.TCOOLTHRS(0);
}

void Robot::WaitUntilTouch(uint8_t touch_pin) {
    Serial.println("Varakozas erintesre...");
    while (touchRead(touch_pin) < 30000) {
        _bno.update(); // Fontos: frissitjuk a szenzort, hogy a yaw valtozzon!
        float current_yaw = _bno.getYaw();
        Serial.println("Current Yaw: " + String(current_yaw));
        delay(50);
    }
    Serial.println("Erintes erzekelve! Indulas...");
    delay(500);
}

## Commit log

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2025-05-22 feat(motor): Add L298N motor controller test code
    Creates a new PlatformIO project to test the L298N motor driver. This initial code is designed to verify basic motor control functionalities like forward, reverse, and speed adjustments.
    [main.cpp]
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2025-07-09 docs: Add initial circuit diagrams and media
    This commit adds the first version of the circuit diagrams in the 'Circuit' directory. It also includes supporting documentation and media files to visually represent the hardware setup.
    [Adafruit 3.5in 480x320 FeatherWing Rev B.kicad_pcb, Adafruit 3.5in 480x320 FeatherWing Rev B.kicad_sch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]
2025-07-09 feat(motor): Integrate two motors with HC-SR04 sensor
    Creates a new project that combines two A4988-driven stepper motors with an HC-SR-04 distance sensor. This is the first step towards creating an autonomous, obstacle-avoiding robot base.
    [main.cpp]
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2025-07-09 feat(kicad): Create version 0.2 of the main circuit
    Introduces a new iteration of the main robot PCB design, version 0.2. This KiCad project, located in 'Circuit/kicad/robot_v2', represents a significant update to the electronic design.
    [3v3_psu.kicad_sch, 4pcs TMC2240.kicad_sch, 5v_psu.kicad_sch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]
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2025-07-09 fix(motor): Reduce TMC2209 RMS current
    Adjusts the configuration for the TMC2209 drivers to lower the `rms_current` setting. This is likely done to prevent overheating of the motors or drivers, reduce noise, or conserve power.
    [main.cpp]
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2025-07-09 feat(kicad): Advance PCB to v0.3 and add EV3 color sensor test
    Updates the main robot PCB design to version 0.3 ('Robot fő nyák_v3') with new features and refinements. Simultaneously adds a v0.1 test program for the Lego EV3 color sensor.
    [CM4IOv5-B_Cu.gbr, CM4IOv5-B_Mask.gbr, CM4IOv5-Edge_Cuts.gbr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]
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2025-07-09 chore: Update web page and save KiCad progress
    This commit includes miscellaneous updates. The project's webpage (`web/index.html`) has been modified, and various KiCad project files have been saved, reflecting ongoing design work.
    [4x tmc5160.kicad_sch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]
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2025-07-09 chore(kicad): Update KiCad design files
    This commit includes various updates and saves to the KiCad project files, reflecting incremental progress on the PCB and schematic designs.
    [3v3_psu.kicad_sch, 4pcs TMC2240.kicad_sch, 4x tmc5160.kicad_sch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]
2025-07-09 feat(altium): Add initial Altium Designer project (v0)
    Creates the first version of a circuit design project using Altium Designer. The project files are located in 'Circuit/altium/robot', marking an exploration of alternative EDA software.
    [4x tmc5160.PrjPcb, 4x tmc5160.SchDoc, 4x tmc5160.SchLib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]
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2025-07-09 refactor(camera): Refine center-screen color detection logic
    This commit adjusts the color detection algorithm in the OpenCV script. To improve stability and reduce sensitivity to sensor noise, the method was changed from reading a single pixel to analyzing a 5x5 region and calculating the mode of the hue values. The commit reflects an experimental stage to find the most reliable approach.
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2025-07-09 docs: Update circuit diagrams and datasheets
    This commit updates the electronic design documentation. It includes changes to the KiCad/Altium circuit files and adds new or updated component datasheets to the 'Datasheets' directory.
    [4x tmc5160.PrjPcb, 4x tmc5160.SchDoc, CM5IO.PcbDoc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]
2025-07-09 fix(kicad): Correct I2C schematic and add new datasheets
    This commit resolves bugs in the I2C bus wiring on the main PCB schematic. It also expands the project's documentation by adding several new component datasheets.
    [4x tmc5160.kicad_sch, BNO085.kicad_sch, CM4IOv5.kicad_sch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]
2025-07-09 refactor(kicad): Simplify PCB by removing redundant fan controller
    This commit refines the main KiCad PCB design by removing the external PWM fan controller circuit. This simplification is possible because the Raspberry Pi CM5 provides its own built-in fan control. 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
    [CM5IO.kicad_sch]
2025-07-09 feat(kicad): Add BNO085 IMU and level shifters to PCB
    Updates the KiCad schematic and layout to include a BNO085 9-DOF IMU for orientation sensing. Also adds I2C level shifter ICs to ensure compatibility between 5V and 3.3V components and fixes related bugs.
    [4x tmc5160.kicad_sch, BME280.kicad_sch, BNO085.kicad_sch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]
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2025-07-09 refactor(kicad): Perform significant PCB update
    This commit contains a substantial update to the main PCB layout in KiCad. Changes likely include major rerouting, component repositioning, or adding new circuit blocks.
    [BNO085.kicad_sch, CM5IO.kicad_pcb, untitled.kicad_sch]
2025-07-09 refactor(kicad): Clean up PCB v3.01 and add robot chassis 3D model
    Finalizes and cleans up version 3.01 of the main KiCad PCB, tidying up schematics and layout. Also adds the 3D model files for the v0.1 robot chassis to the 'Robot 3d' directory.
    [15 pin LEGO for robot_0.1.stl, 4x tmc5160.kicad_sch, BME280.kicad_sch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]
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2025-07-09 refactor(comm): Refine and enhance UART LED control logic
    This commit improves upon the previously implemented UART LED control system. The logic has been refined for greater reliability and responsiveness, addressing shortcomings of the initial version and resulting in a more robust implementation.
    [main.py]
2025-07-10 M.2 power rail fixed
    [CM5IO.kicad_sch, PCIe-M2.kicad_sch]
2025-07-10 Kicad update: power rails v1.0, todo: hc-sr-04 as6500 ic review shift registers change to MCP23S17_SO
    [AS6500.kicad_sch, Battery-circuit.kicad_sch, CM5IO.kicad_sch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]
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2025-07-11 kicad v0.1 footprint- assing spi finish
    [4x tmc5160.kicad_sch, AS6500.kicad_sch, BME280.kicad_sch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]
2025-07-11 kicad i2c and spi mux fixed and bugfixs
    [Battery-circuit.kicad_sch, CM5IO.kicad_pcb, CM5IO.kicad_sch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]
2025-07-12 kicad update new readme media updates the circuit is 95% finished
    [4x tmc5160.kicad_sch, ADS8688 .kicad_sch, AS6500.kicad_sch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]
2025-07-13 readme updated kicad circuit V1
    [4x tmc5160.kicad_sch, ADS8688 .kicad_sch, AS6500.kicad_sch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]
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2025-08-21 kicad final circuit 1
    [0.2 bom.csv, 0.3 bom.csv, Battery-circuit.kicad_sch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]
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2025-08-23 kicad update (first try pcb, added JB leds, rename i2c headers footprint)
    [CM5IO.kicad_pcb, CM5IO.kicad_sch, I2C_devices.kicad_sch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]
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2025-09-07 new 2 pcb schematics in v4.0 folder, psu sch finish, bad pcb, high speed: bad pcb and sch
    [4x tmc5160.kicad_sch, ADS8688 .kicad_sch, AS6500.kicad_sch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]
2025-09-08 kicad v4 psu pcb clean
    [4x tmc5160.kicad_sch, Battery-circuit.kicad_sch, H-bridge.kicad_sch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]
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2025-09-15 kicad psu pcb finish psu
    [Battery-circuit.kicad_sch, H-bridge.kicad_sch, INA226.kicad_sch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]
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2025-09-16 kicad FINISH PSU PCB
    [PCA9531PW.kicad_sch, PSUs.kicad_sch, fpp-kábel.kicad_sch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]
2025-09-16 kicad pcb soldermask update
    [psu.kicad_pcb]
2025-09-17 PSU FINISH BOARD NO DRC,ERC,DFM ERRORS
    [Battery-circuit.kicad_sch, PCA9531PW.kicad_sch, dc-power-off.kicad_sch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]
2025-10-01 PSU bugfixes
    [4x tmc5160.kicad_sch, ADS8688 .kicad_sch, AS6500.kicad_sch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]
2025-10-06 V4.1.7 PSU V1.0 debug Card
    [YD-ESP32-S3.kicad_sch, dc-power-off.kicad_sch, power-management.kicad_sch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]
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2025-10-20 added psu start delay rc tag, high speed first inner and outboard impedance calculations
    [CM5_GPIO.kicad_sch, CM5_HighSpeed.kicad_sch, I2C_devices.kicad_sch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]
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2025-11-03 kicad: high speed V2.2 Circuit finish psu bom update
    [BME280.kicad_sch, BNO085.kicad_sch, CM5_GPIO.kicad_sch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]
2025-11-27 finished high-speed panel schematic and first try to doute gpios
    [BME280.kicad_sch, BNO085.kicad_sch, CM5_GPIO.kicad_sch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]
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2025-12-05 High Speed all routed, DRC, DFM shows 0 error (without silkscreen layers)
    [CM5_GPIO.kicad_sch, CM5_HighSpeed.kicad_sch, MCP3208.kicad_sch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]
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

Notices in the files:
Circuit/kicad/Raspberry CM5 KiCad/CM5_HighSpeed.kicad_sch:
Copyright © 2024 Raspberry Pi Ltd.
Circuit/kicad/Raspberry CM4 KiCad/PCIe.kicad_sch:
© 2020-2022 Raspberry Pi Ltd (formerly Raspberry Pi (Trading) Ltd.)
